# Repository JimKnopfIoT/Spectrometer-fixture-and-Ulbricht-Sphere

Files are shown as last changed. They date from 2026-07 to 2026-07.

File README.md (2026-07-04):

# Spectrometer-fixture-and-Ulbricht-Sphere
3D printable parts for Spectrometer and an Ulbricht Sphere, created in Rhino 8

Recently i came across Les Wrigth's interesting PySpectrometer repo's (https://github.com/leswright1977/PySpectrometer2).
He made a very stable holder for the Spectrometer and a Pi-Camera and connected it to a Rasperry Pi and a Display. Very impressive project. 
I decided to build my own device because i wanted to test some UV/IR LEDs and UV/IR Lasers. 
In addition to his repo here on github, he has some very interesting videos about Laser stuff, the Spectrometer project and an Ulbricht Sphere.
The Ulbricht Sphere is a nice addon for experimenting with the PySpectrometer.

I also bought a Spectryx Blue Box which is also a spectrometer with a fiber optic sensor.

For my experiments i designed the parts and 3D printed it.

## 1. Enclosure/fixture for Spectroscope, RPiv2 Camera, 20.000 mAh Powerbank, RPi4, RPi-Display. I followed Les Wrights setup.

The Enclosure consists of 6 parts that are screwed together using M3 Buttonhead Allen socket screws and M3 square nuts.
The Rpi4 and the Display are screwd together and mounted on a slider that fits on top of the fixture. 
The Spectroscope is also mounted on a slider using M3 Buttonhead Allen socket screw and M3 square nut. I used hook'n loop tape to hold it in place.
I also used hook'n loop tape for the Powerbank to prevent it from sliding out of the enclosure.

<p align="center">
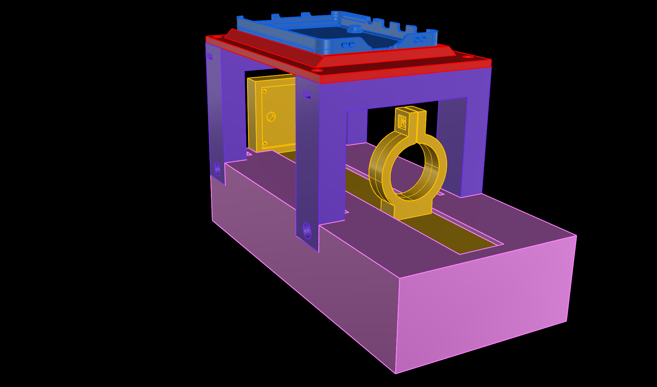
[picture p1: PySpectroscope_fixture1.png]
 
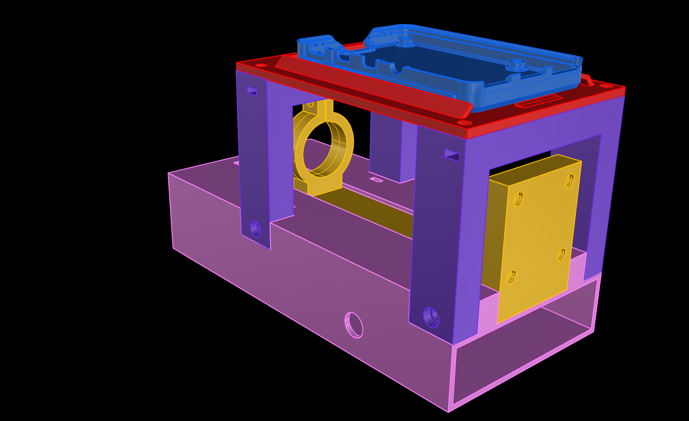
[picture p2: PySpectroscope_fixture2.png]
 
</p>
<p align="center">
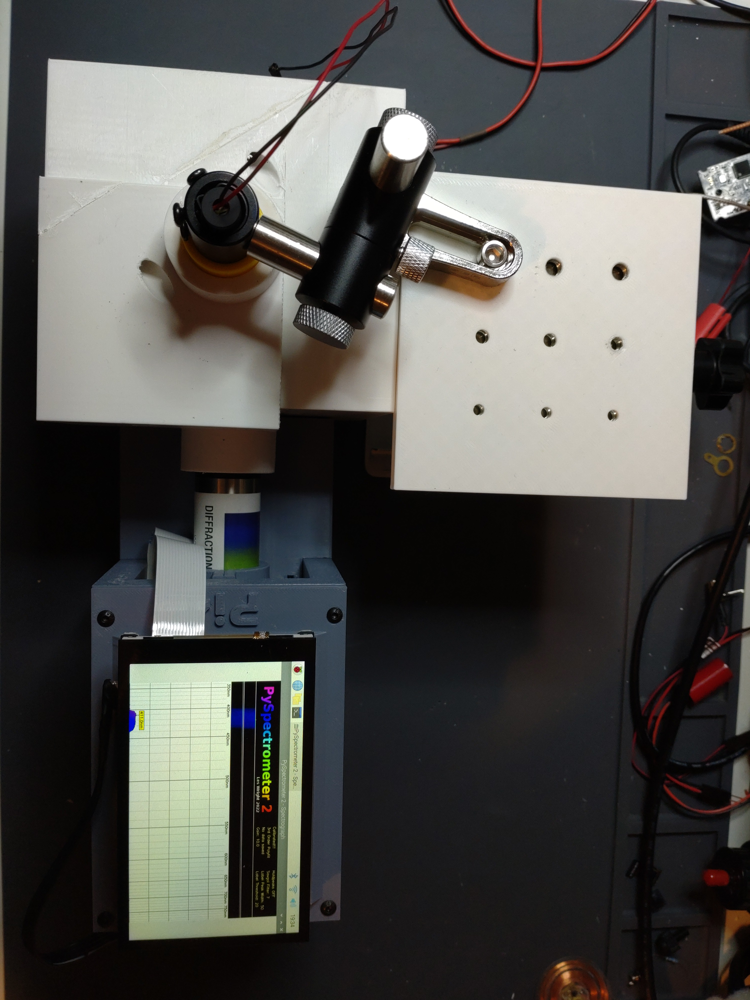
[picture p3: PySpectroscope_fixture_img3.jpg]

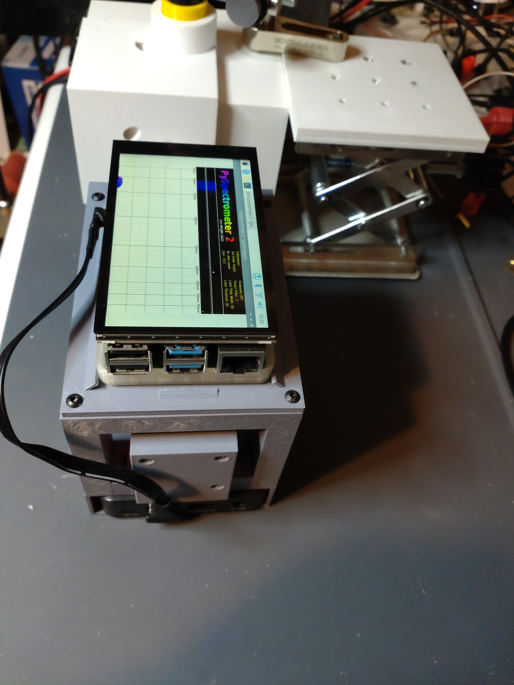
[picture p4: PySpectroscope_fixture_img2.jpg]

</p>
<p align="center">
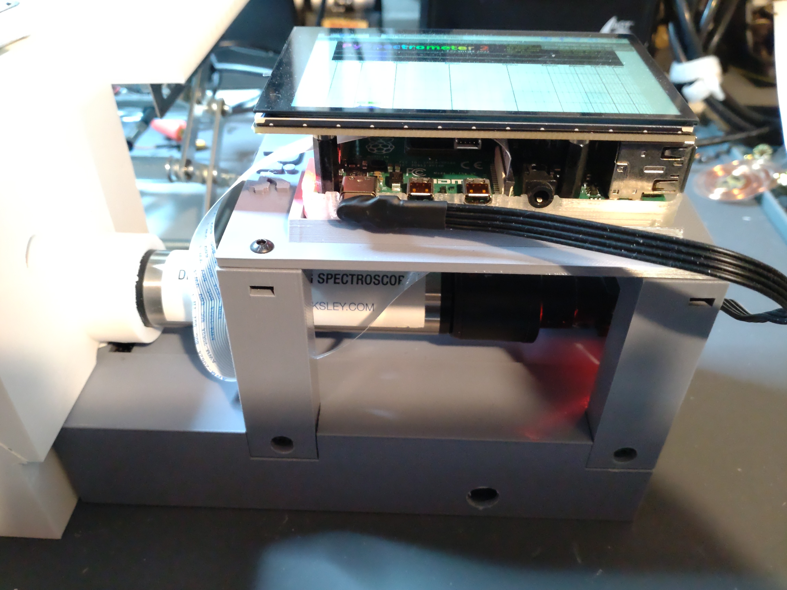
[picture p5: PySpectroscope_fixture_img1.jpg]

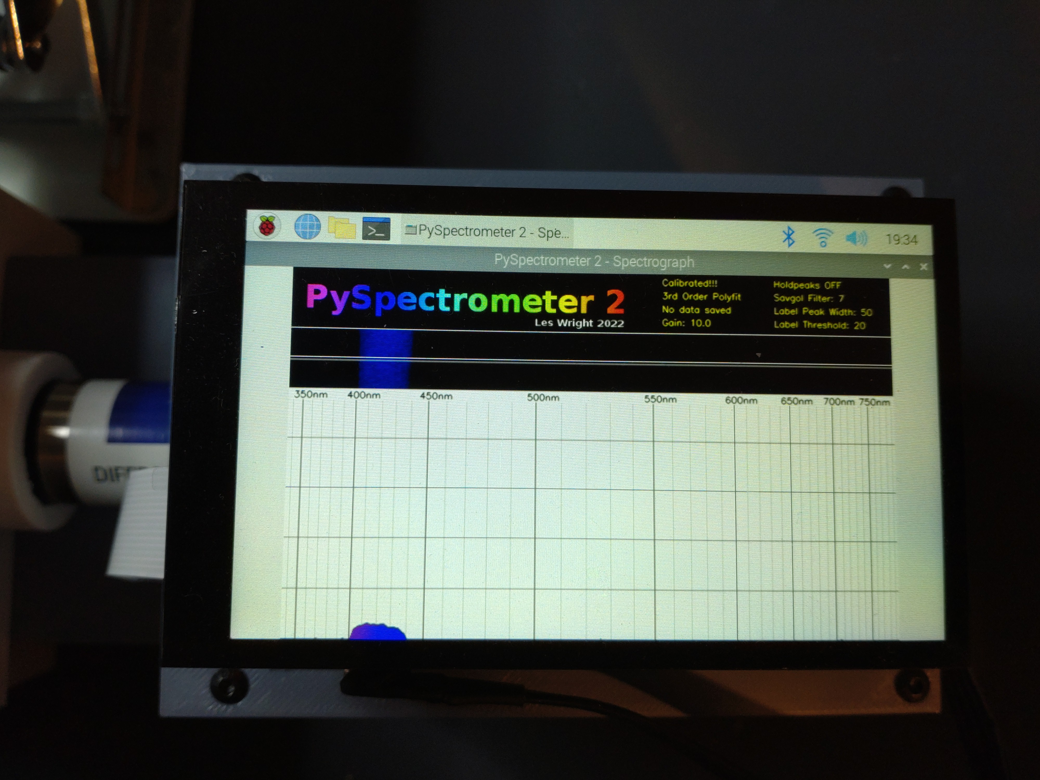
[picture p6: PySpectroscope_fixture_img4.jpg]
 
</p>

## 2. Ulbricht Sphere
I made 2 versions of the Ulbricht Sphere. Both consist of 2 parts that are screwd togehter using M3 Buttonhead Allen socket screws and M3 square nuts.
Both are designed to be fit to the PySpectroscope enclosure/fixture. The light source can be applied from the top or from the side by rotating the Sphere by 90 degree.
The main different is, the first one is clearly recognizable as a sphere. The disadvantage is that the cut surface of both halves is exactly where the laser beam hits the surface of the sphere.

The second version looks like a cube from the outside. I rotated the cutting surface by 45° so that the laser beam hits an undisturbed surface.
As described by Les Wright in his video, the surface of the Ulbricht Sphere has to be painted with Bariumsulfat / BaSO4. 
BaSO4 looks like powder. To apply it to the surface, you have to liquefy it and bind it so that it adheres to the surface.
I tried the mixture reccomended by Les Wright but it dried poorly, cracked after drying, and did not adhere to the surface properly. It crumbled. 

I prepared the second Sphere before painting with adhesive primer. I then used a mixture from "Kremer Pigmente, Germany". It's also BaSO4, they called it Blanc Fix. Instead of PVA glue they use something called Klucel(TM) G (Hydroxypropylcellulose) and also demineralised water. This mixture adhered much better to the surface. After some trials i used a paintbrush to apply the mixture to the surface and the cut surface.

<p align="center">
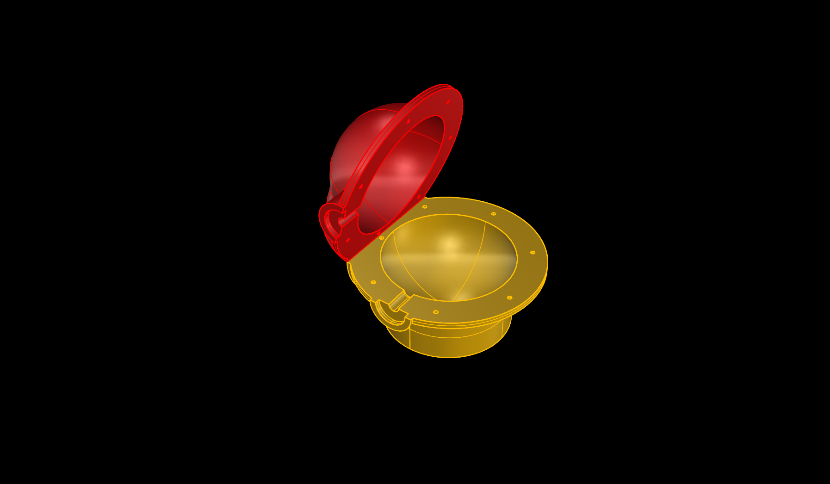
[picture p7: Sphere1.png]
 
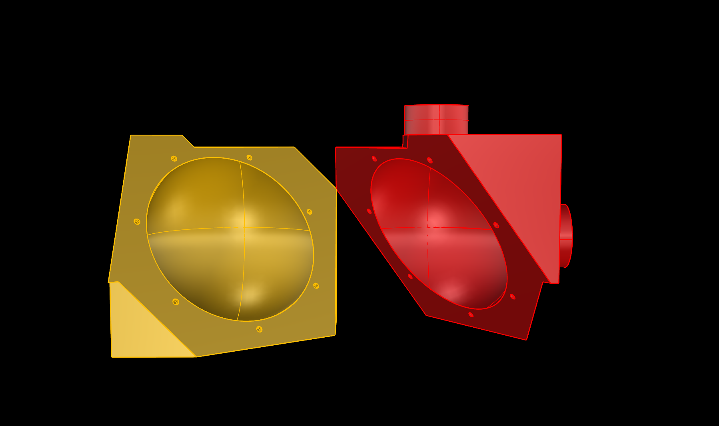
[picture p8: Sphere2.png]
 
</p>
   
## 3. Holder for fiber optic sensor of the Spectryx Blue Box to fit in the Ulbricht Sphere

I designed an adapter for the fiber optic cable to fit it's end to the Ulbricht Sphere exit point. I also designed adapters to center the laser to the entry point of the Sphere.
I use 3 axis holders from Aliexpress to keep the laser modules in position. If you use Octave with the Spectryx Blue Box make sure to edit the file to point to the correct device.

<p align="center">
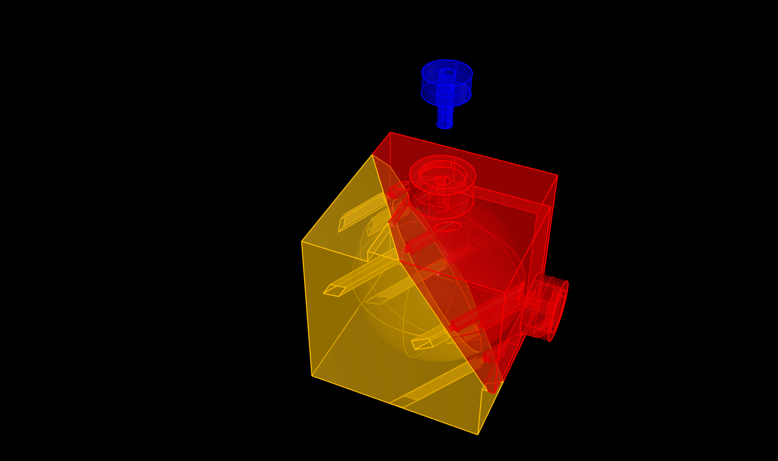
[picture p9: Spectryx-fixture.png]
 
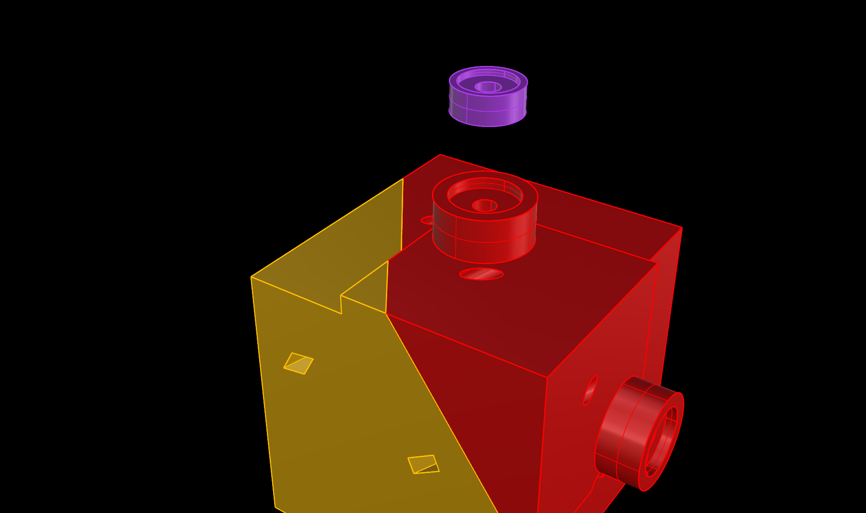
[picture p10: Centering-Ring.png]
 
</p>
<p align="center">
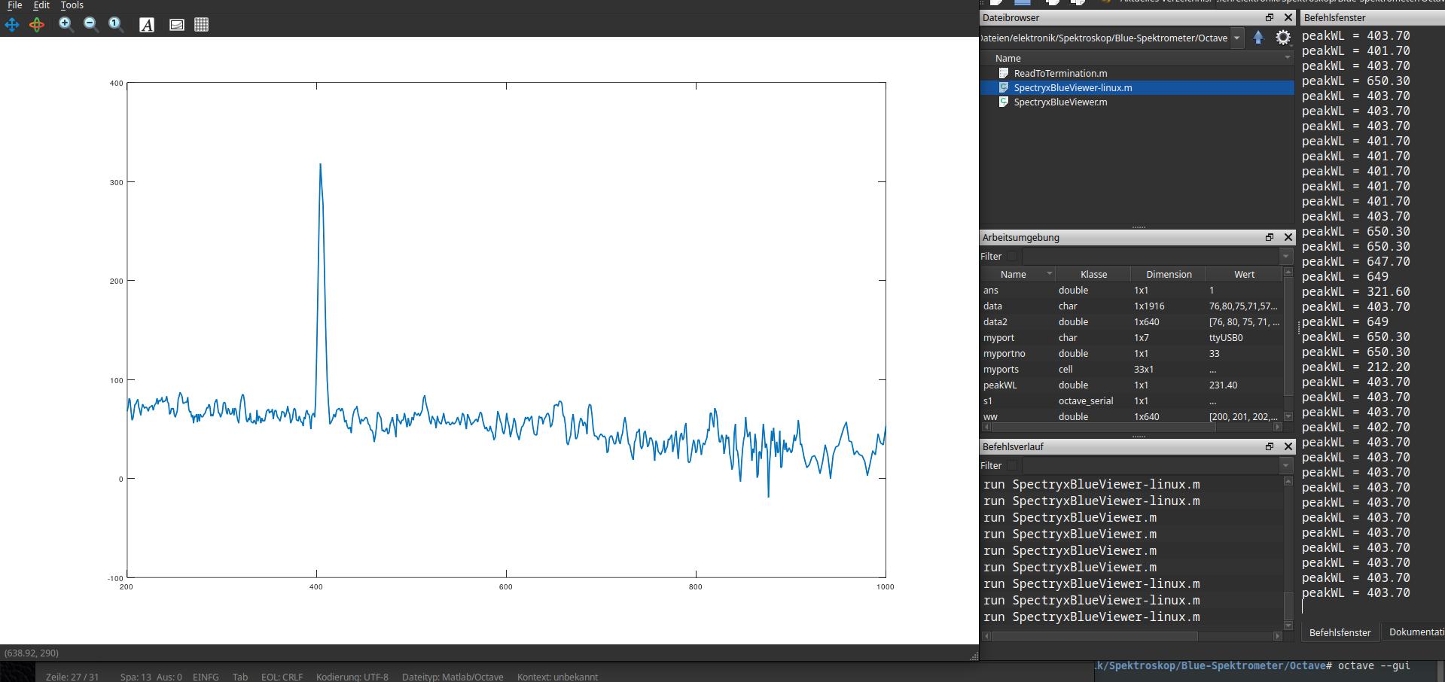
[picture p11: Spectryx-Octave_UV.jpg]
 
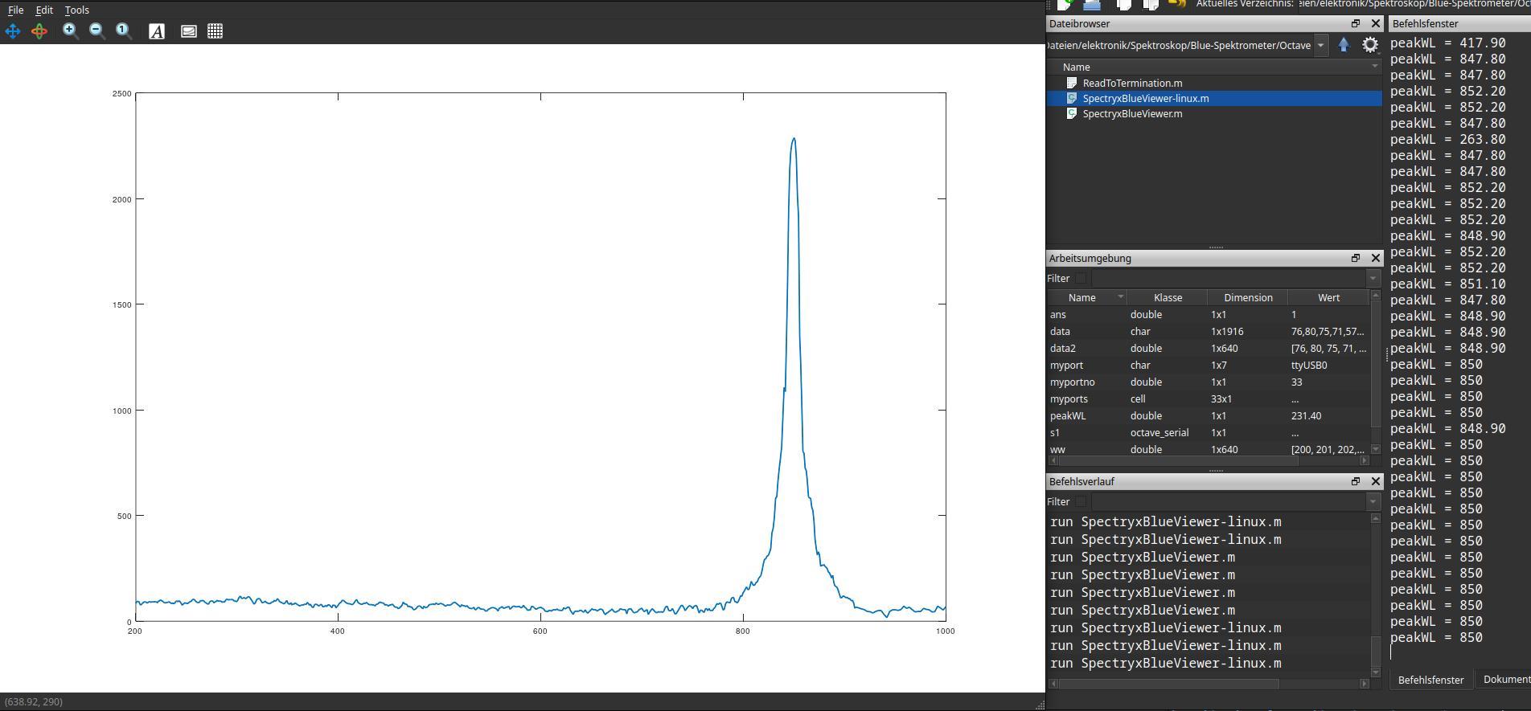
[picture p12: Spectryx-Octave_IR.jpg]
 
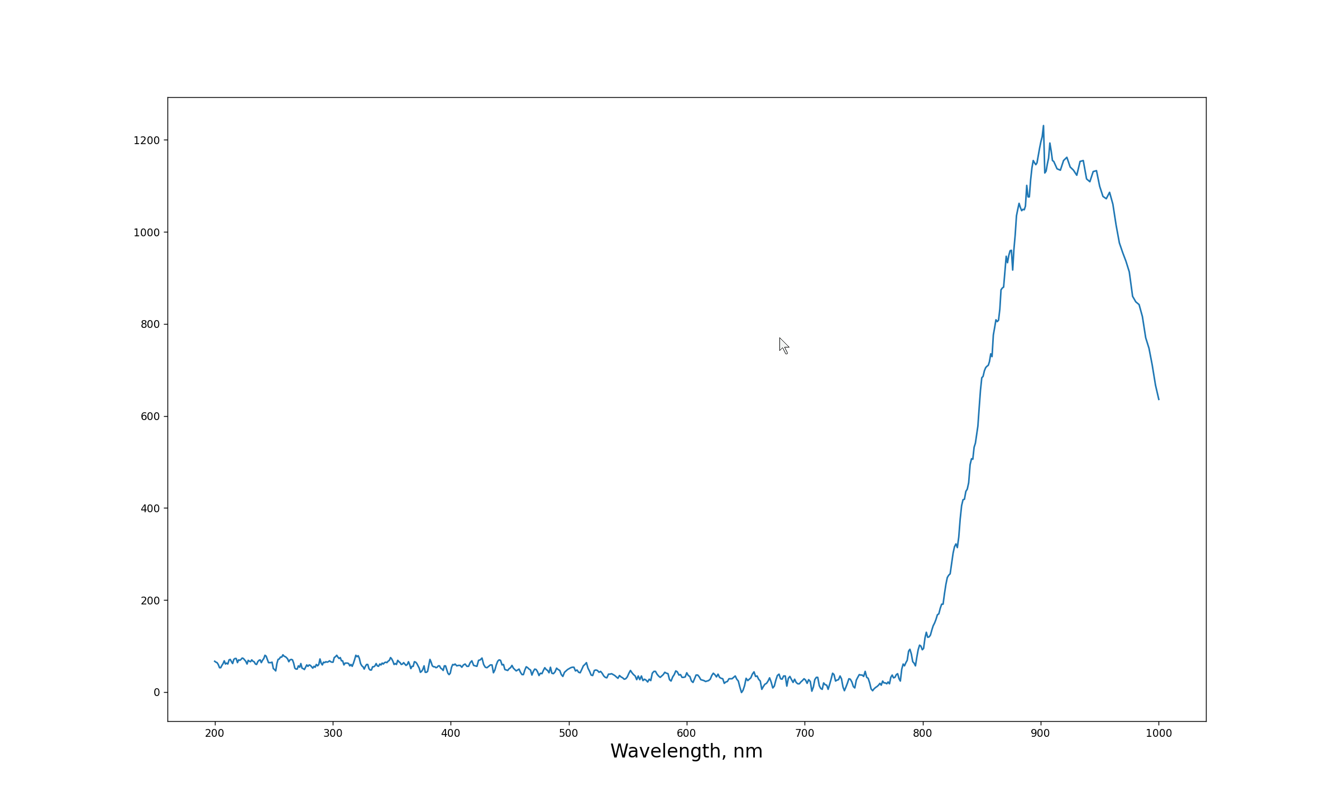
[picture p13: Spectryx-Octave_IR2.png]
 
</p>

Using the Ulbricht Sphere for IR LED doesn't work for me. The light emitted from the LED is too weak.
Therefor i made a adjustable adapter for the Spectryx Blue Box Sensor. From bottom side the LED fits in. 
The Topside fits the Fiber optic sensor. That also prevent other light reaching the sensor. 
As you can see in the image below, the IR-LED emmitted light at 1,42 V/12,5mA at 958,3 nm (peak).

<p align="center">
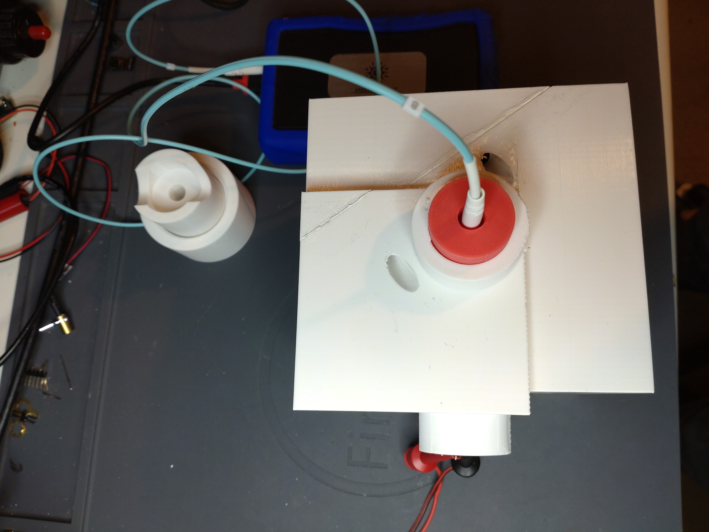
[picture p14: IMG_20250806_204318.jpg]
 
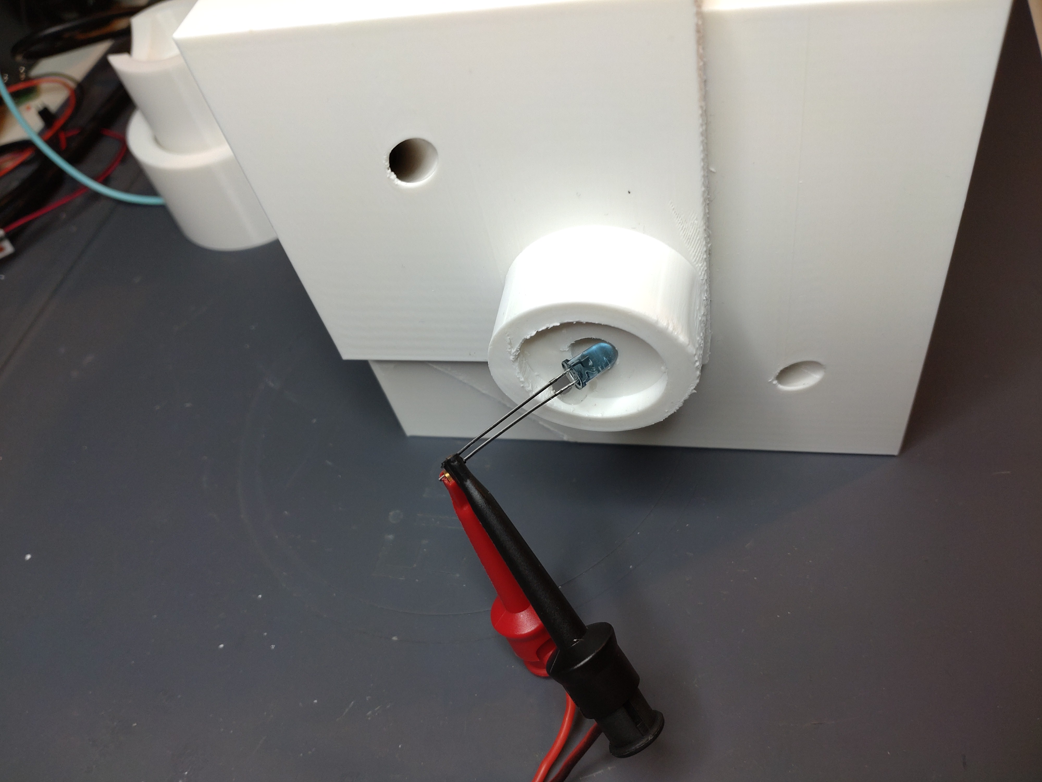
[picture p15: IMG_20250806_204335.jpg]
 
</p>
<p align="center">
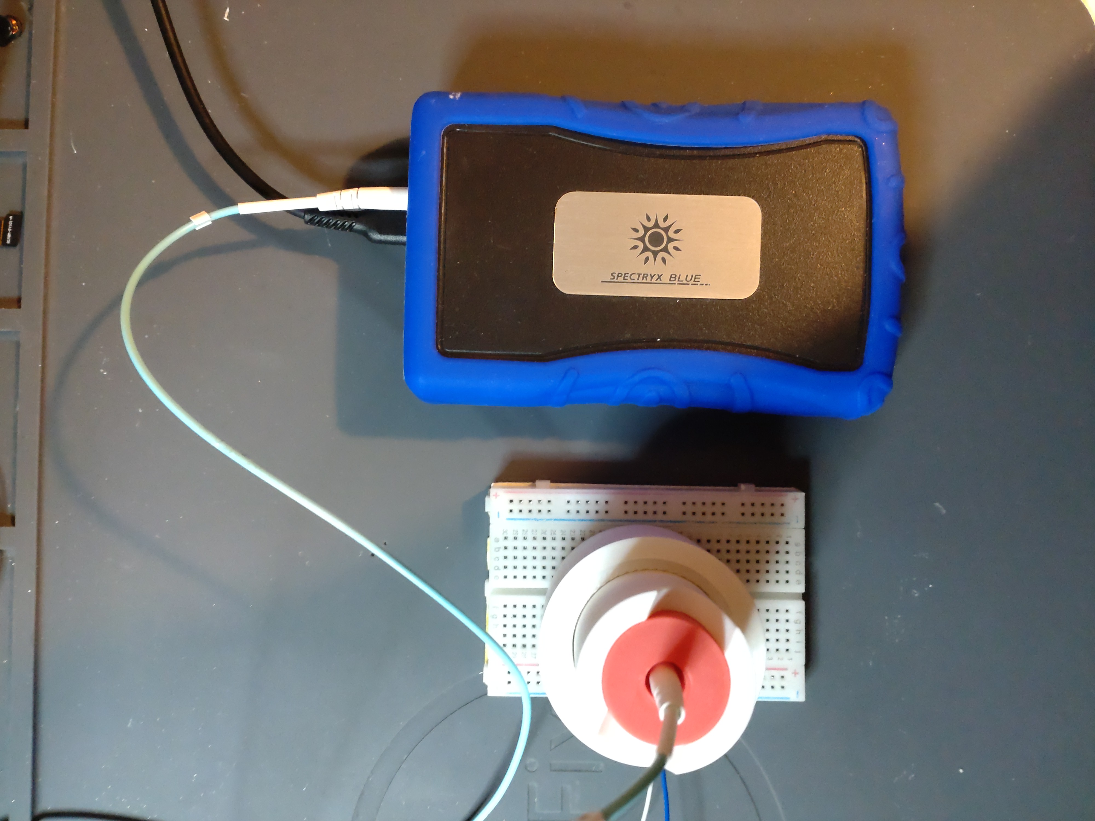
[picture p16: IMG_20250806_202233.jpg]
 
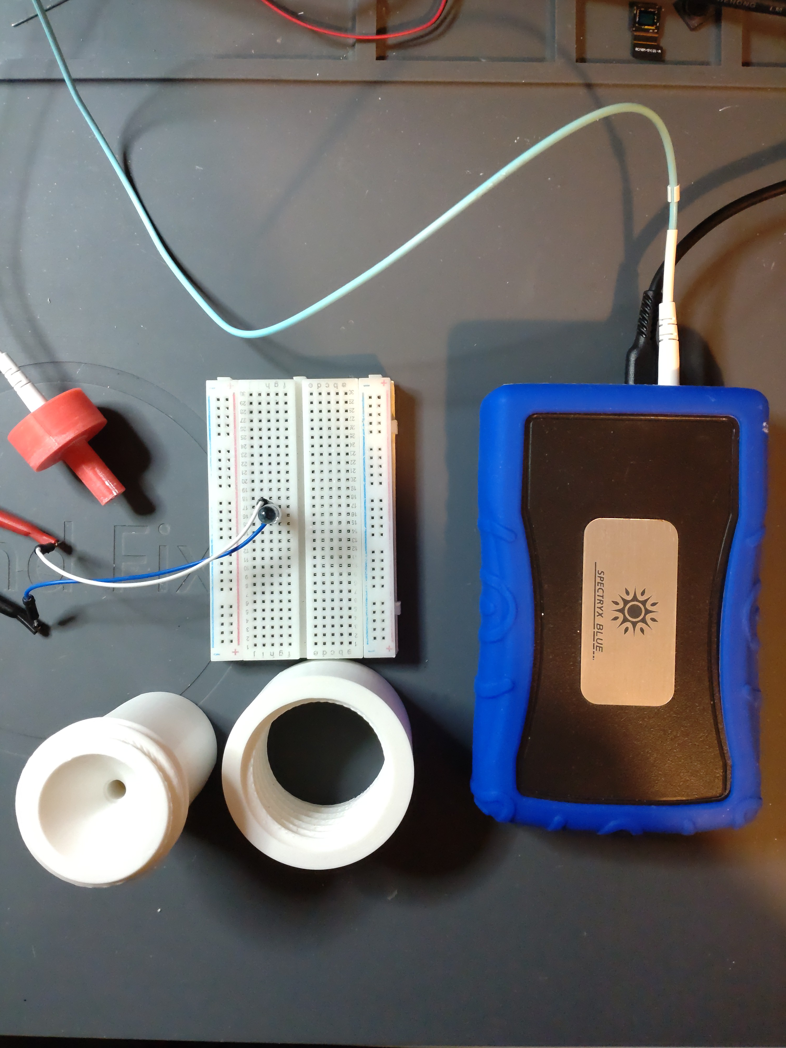
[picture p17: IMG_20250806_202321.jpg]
 
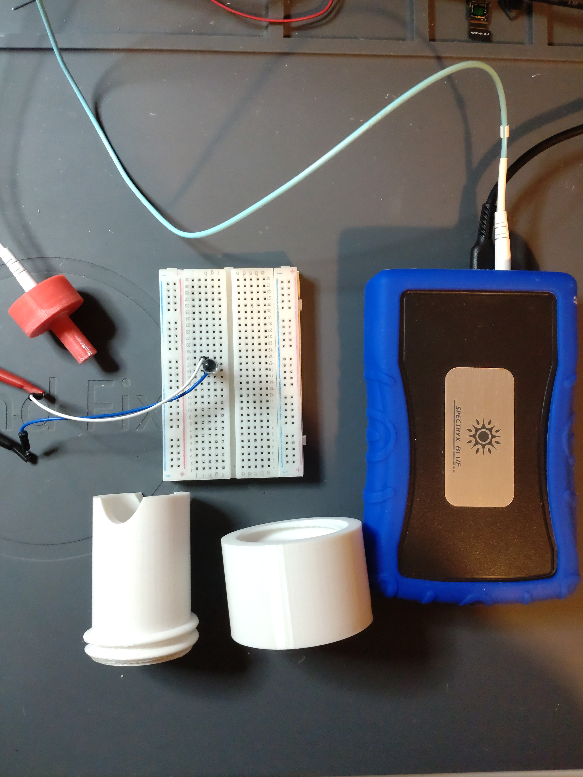
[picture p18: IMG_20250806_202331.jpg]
 
</p>
<p align="center">
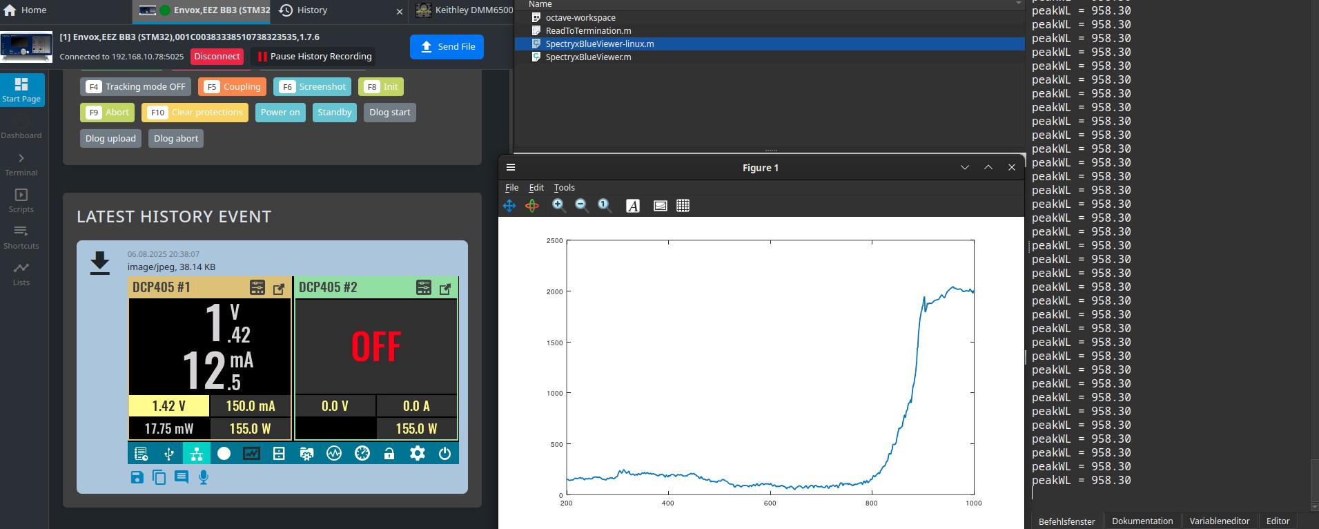
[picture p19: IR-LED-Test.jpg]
 
</p>
<p align="center">
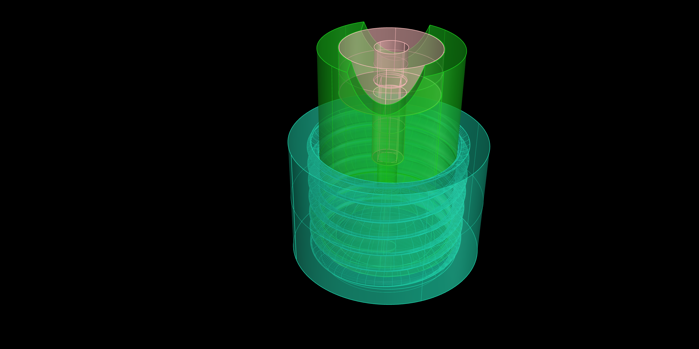
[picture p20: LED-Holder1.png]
 
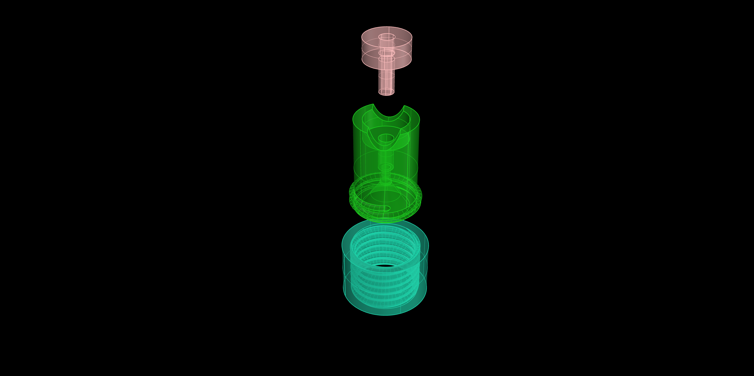
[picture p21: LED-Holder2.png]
 
</p>
<p align="center">
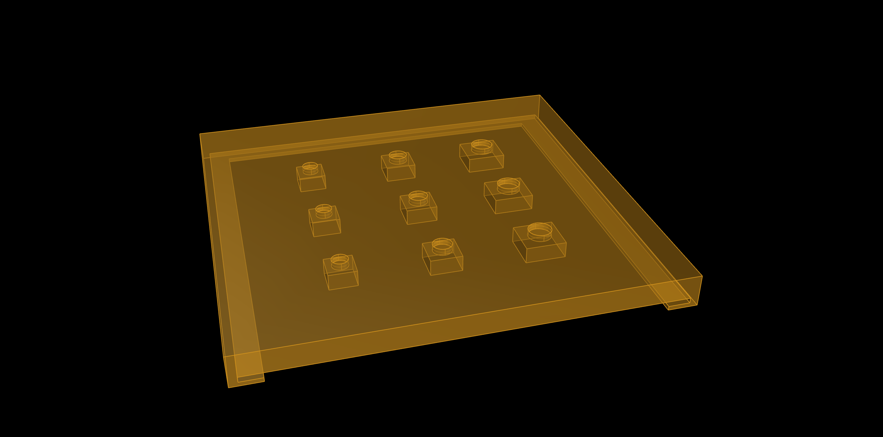
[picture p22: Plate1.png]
 
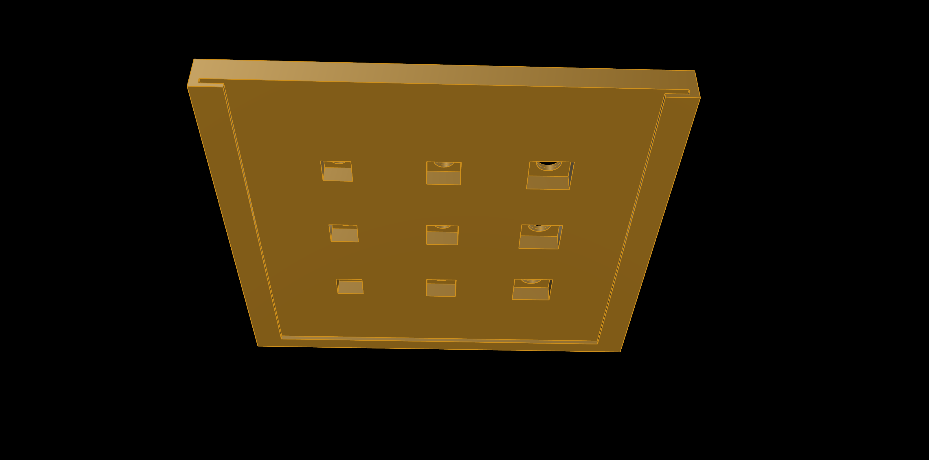
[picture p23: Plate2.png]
 
</p>

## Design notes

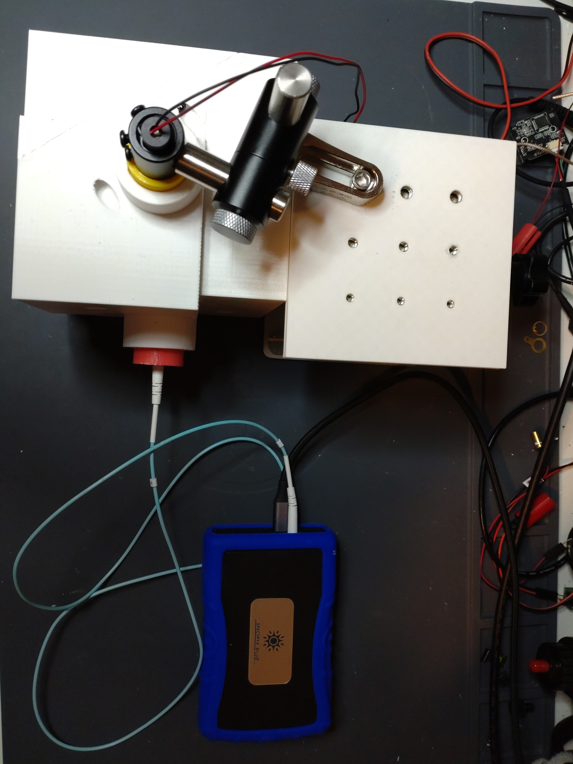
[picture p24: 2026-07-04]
Spectryx_Ulbricht-Sphere.jpg

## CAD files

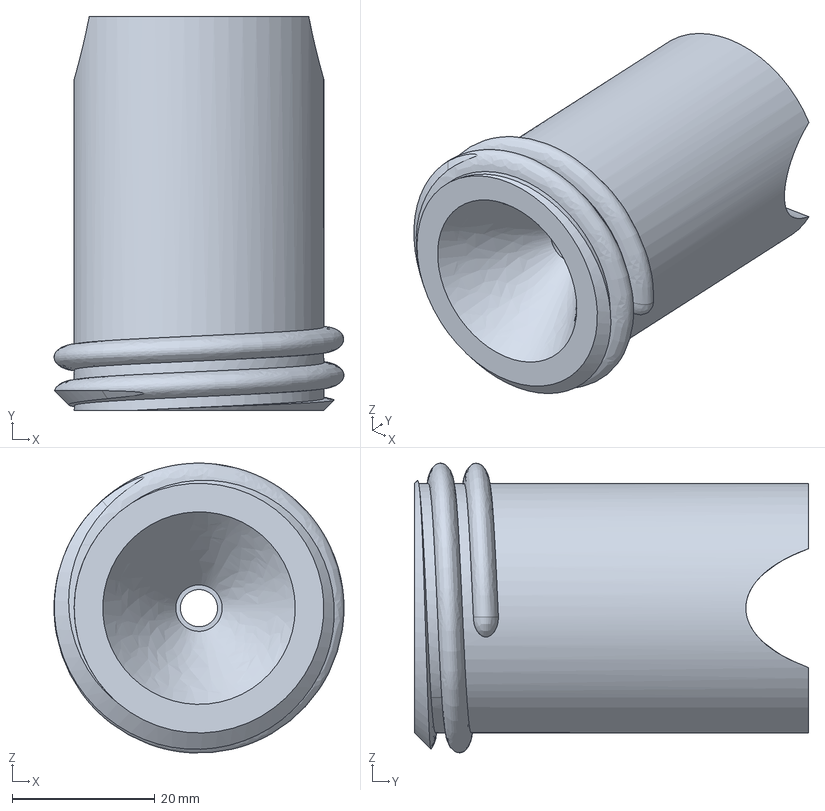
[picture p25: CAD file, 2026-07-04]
LED-Halter.stp
40.6 x 55.2 x 40.6 mm

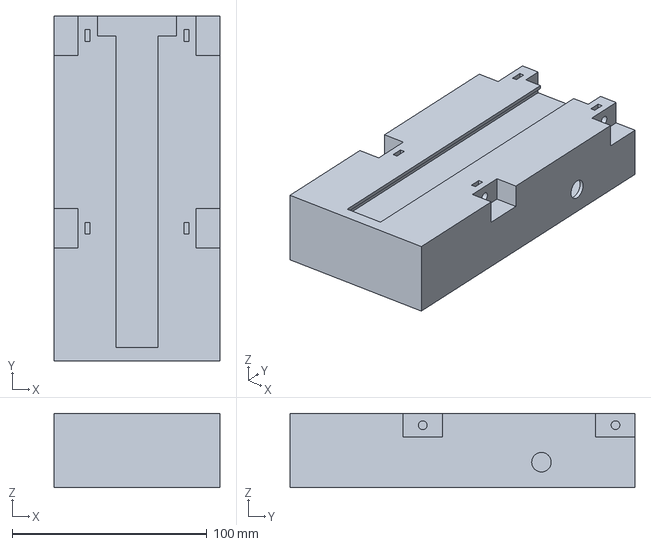
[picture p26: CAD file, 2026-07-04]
PySpectroscope_fixture_1.stp
85.0 x 177.0 x 38.0 mm

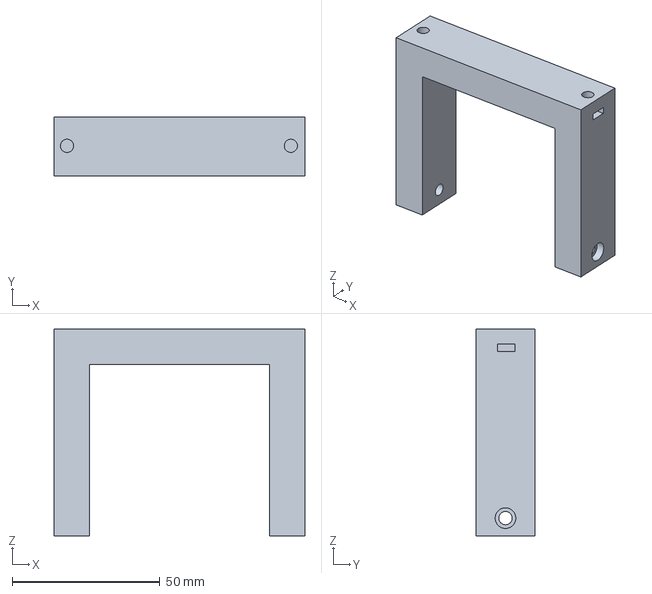
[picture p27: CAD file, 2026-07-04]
PySpectroscope_fixture_4.stp
85.0 x 20.0 x 70.0 mm

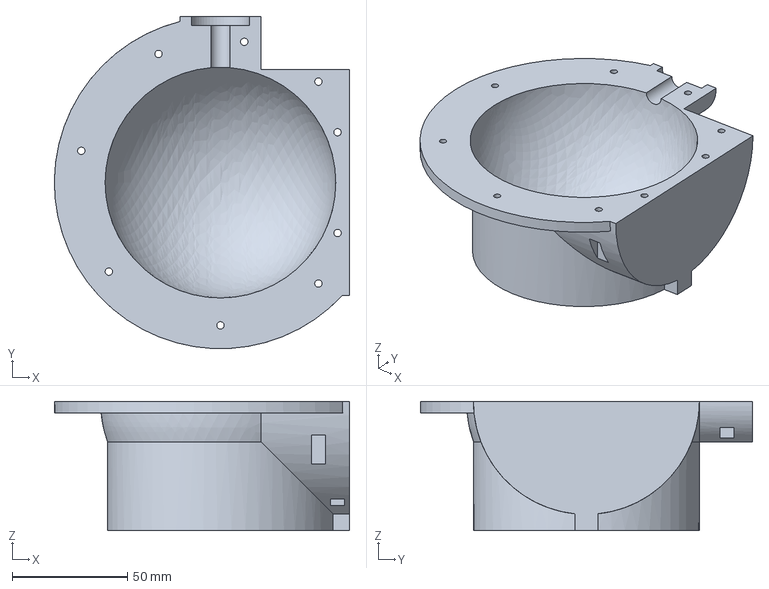
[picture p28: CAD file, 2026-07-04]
Ulbricht-Sphere1_part2.stp
128.0 x 143.9 x 56.0 mm

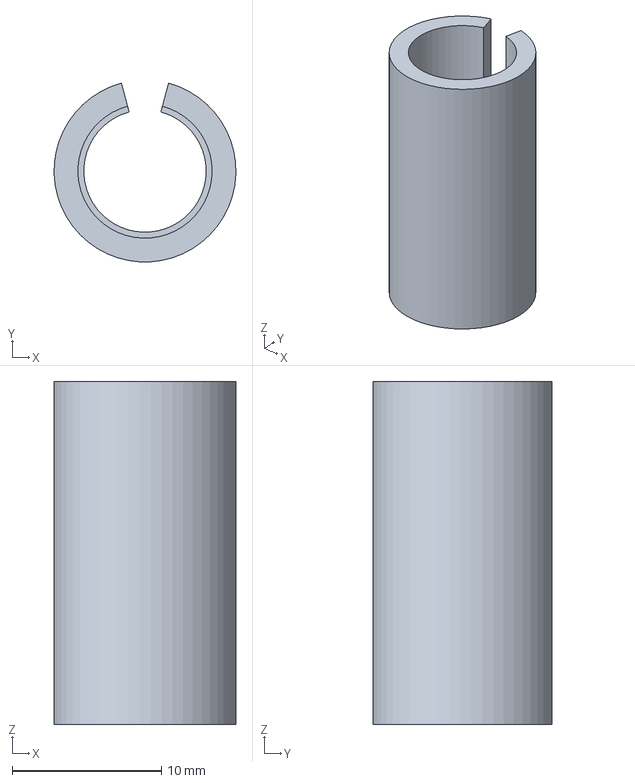
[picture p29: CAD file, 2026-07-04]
Laserhead-holder_8mm.stp
12.2 x 12.0 x 23.0 mm

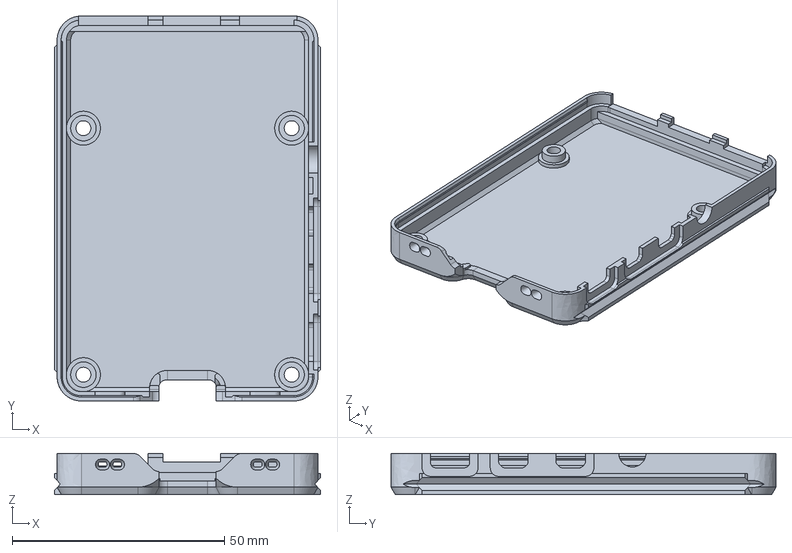
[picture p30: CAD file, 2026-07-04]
PySpectroscope_fixture_6.stp
62.6 x 90.6 x 9.70 mm

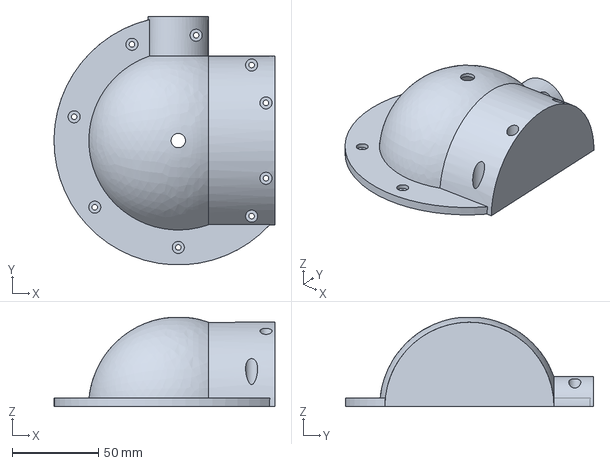
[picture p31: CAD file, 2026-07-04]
Ulbricht-Sphere1_part1.stp
128.0 x 143.9 x 51.8 mm

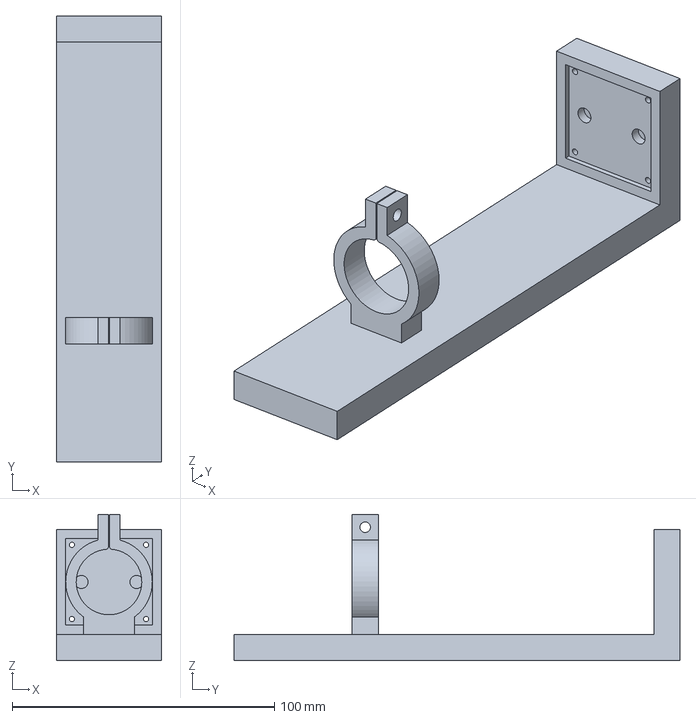
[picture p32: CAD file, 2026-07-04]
PySpectroscope_fixture_2.stp
40.0 x 170.0 x 55.8 mm

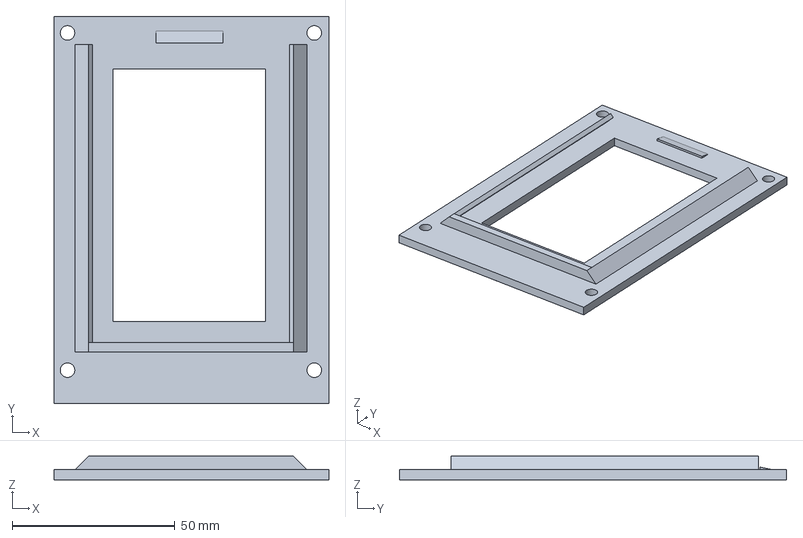
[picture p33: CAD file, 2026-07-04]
PySpectroscope_fixture_5.stp
84.4 x 118.9 x 7.35 mm

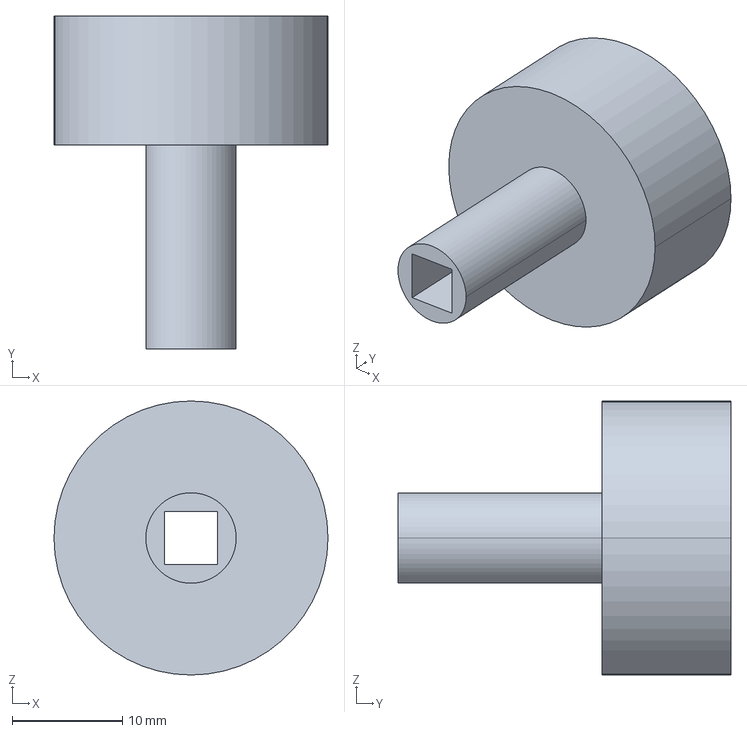
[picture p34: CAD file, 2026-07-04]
Sensor-holder_bigger2.stp
24.8 x 30.2 x 24.8 mm

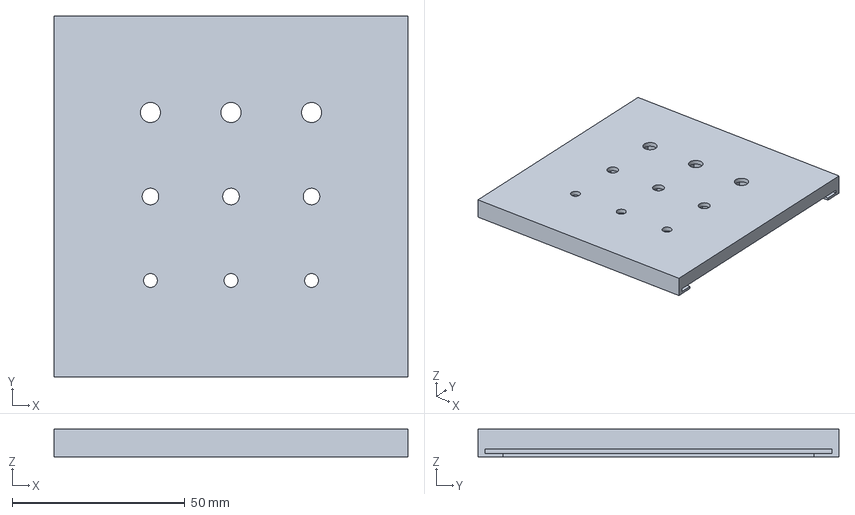
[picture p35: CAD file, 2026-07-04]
Plate.stp
102.4 x 104.4 x 8.00 mm

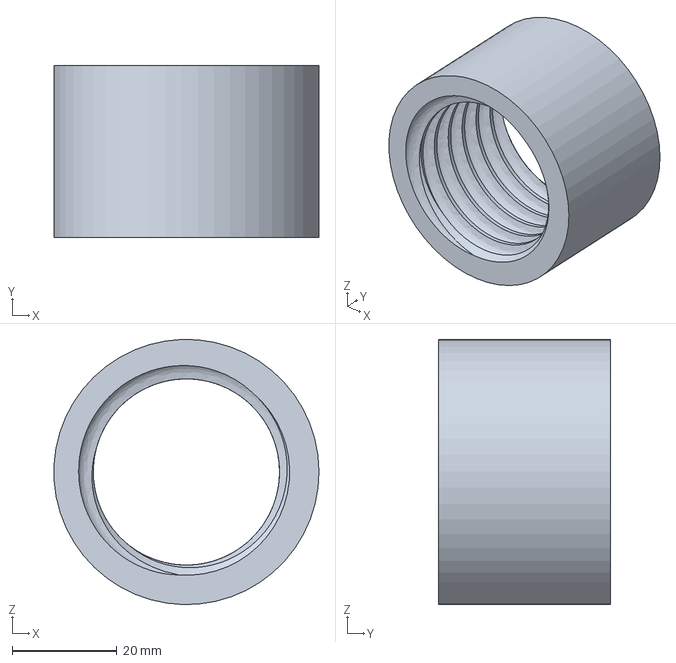
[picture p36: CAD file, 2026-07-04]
LED-Holder-adjustment.stp
50.6 x 32.8 x 50.6 mm

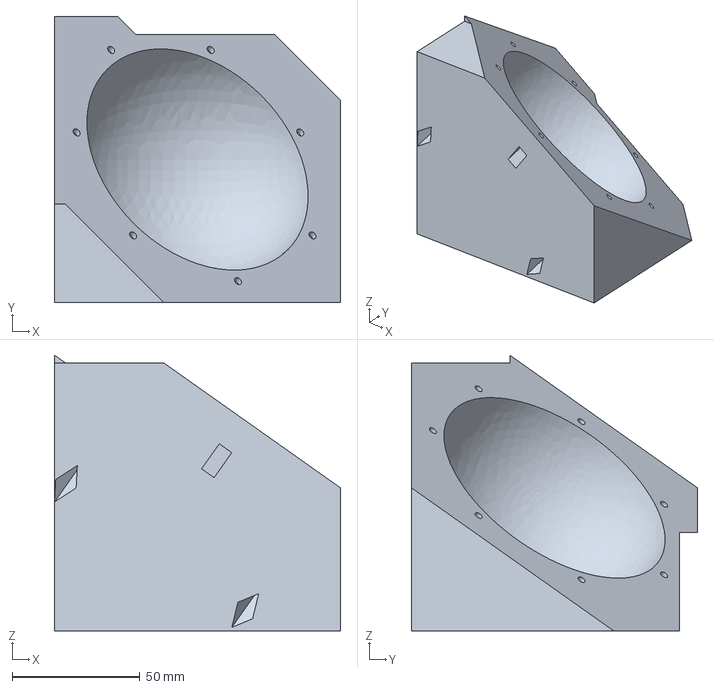
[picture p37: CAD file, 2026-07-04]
Ulbricht-Sphere2_part1.stp
112.0 x 112.0 x 108.0 mm

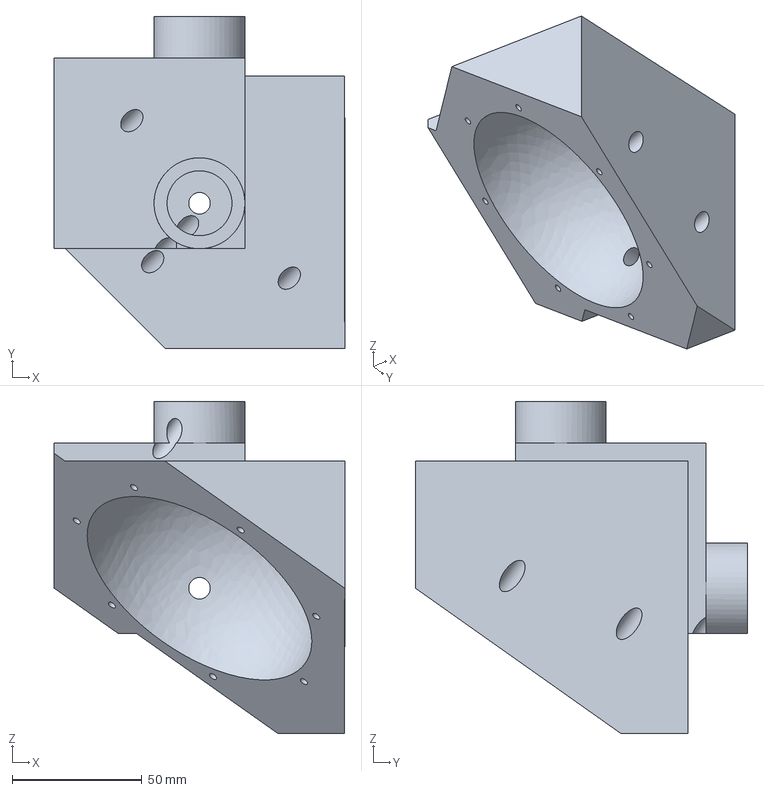
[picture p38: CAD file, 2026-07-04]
Ulbricht-Sphere2_part2.stp
112.0 x 128.0 x 128.0 mm

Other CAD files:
LED-Holder.stl
Laserhead-holder_6mm.stp
PySpectroscope_fixture_3.stp
LED-Holder-adjustment.stl
Laserhead-holder+Plate.3dm
Laserhead-holder_6mm.stl
Laserhead-holder_8mm.stl
Plate.stl
PySpectroscope_fixture.3dm
PySpectroscope_fixture_1.stl
PySpectroscope_fixture_2.stl
PySpectroscope_fixture_3.stl
PySpectroscope_fixture_4.stl
PySpectroscope_fixture_5.stl
PySpectroscope_fixture_6.stl
Sensor-holder_bigger2.stl
Ulbricht-Sphere1.3dm
Ulbricht-Sphere1_part1.stl
Ulbricht-Sphere1_part2.stl
Ulbricht-Sphere2.3dm
Ulbricht-Sphere2_part1.stl
Ulbricht-Sphere2_part2.stl
